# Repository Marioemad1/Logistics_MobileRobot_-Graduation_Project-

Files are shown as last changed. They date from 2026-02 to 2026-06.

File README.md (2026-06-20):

# Logistic Autonomous Robot

> A ROS 2 Humble autonomous logistics robot built for indoor navigation, station approach, cargo lifting, and future IoT / vision-assisted operation.

<p align="center">
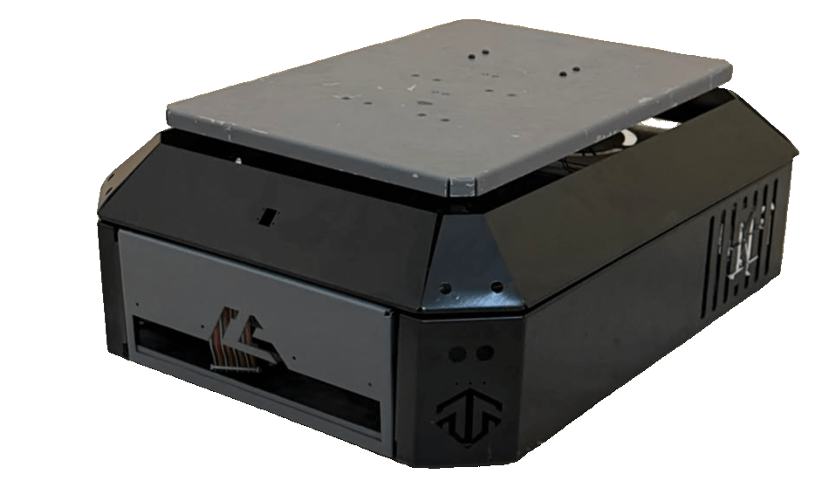
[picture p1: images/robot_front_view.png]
Robot front view placeholder
  
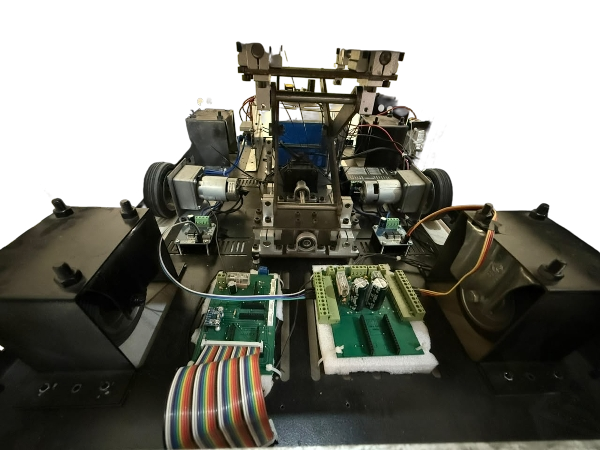
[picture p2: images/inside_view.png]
Robot electronics placeholder
  
</p>

https://github.com/user-attachments/assets/4f5d6dd3-665a-47e2-b4b6-8914b8b3f0d6

---

https://github.com/user-attachments/assets/4580d9f8-e7c1-4550-9aac-f85dd0c8e0f9

---

https://github.com/user-attachments/assets/9e4aa50d-fc3b-4a67-ba5b-2316206a55df

---

## Table of Contents

- [Project Overview](#project-overview)
- [Main Features](#main-features)
- [System Architecture](#system-architecture)
- [Hardware](#hardware)
- [Software Stack](#software-stack)
- [Repository Structure](#repository-structure)
- [ROS 2 Packages](#ros-2-packages)
- [Coordinate Frames and TF Tree](#coordinate-frames-and-tf-tree)
- [Serial Communication Protocol](#serial-communication-protocol)
- [Navigation and Localization](#navigation-and-localization)
- [Manual Engineering Edits](#manual-engineering-edits)
- [Installation](#installation)
- [Building the Workspace](#building-the-workspace)
- [Running the Robot](#running-the-robot)
- [Testing Checklist](#testing-checklist)
- [Troubleshooting](#troubleshooting)
- [Advantages of the Project](#advantages-of-the-project)
- [Roadmap](#roadmap)
- [Safety Notes](#safety-notes)
- [License](#license)

---

## Project Overview

This project is a complete ROS 2 mobile robot system designed for logistics-style operation. The robot is intended to:

1. Build or use a 2D map of an indoor environment.
2. Localize itself using LiDAR odometry and AMCL / EKF localization.
3. Navigate to target points using Nav2.
4. Approach loading / unloading stations.
5. Control a NEMA-driven lifting mechanism through an ESP32.
6. Support future camera-based station alignment and IoT command integration.

The robot was developed around a real physical platform, not only simulation. Because of that, the project includes several hardware-specific solutions such as custom `ros2_control` hardware interfaces, ESP32 serial control, LD06 LiDAR configuration, RF2O laser odometry, and conservative Nav2 tuning for a mechanically challenging differential-drive base.

---

## Main Features

- ROS 2 Humble workspace for a real mobile robot.
- Custom URDF / Xacro robot model with real CAD meshes.
- `ros2_control` integration for:
  - Differential-drive wheel control.
  - NEMA lift command interface.
  - Experimental IMU / LED / sensor interfaces.
- ESP32 serial protocol for motor and lift commands.
- LD06 LiDAR support.
- RF2O LiDAR odometry support.
- Optional EKF fusion using `robot_localization`.
- Nav2 configuration for slow and safe indoor testing.
- AMCL localization on a saved map.
- DWB local planner tuning for a large, unstable robot.
- YOLO-based camera alignment prototype.
- MQTT IoT bridge prototype.
- PS5 controller teleoperation support through `/cmd_vel`.

---

## System Architecture

```mermaid
architecture-beta

    group interface(cloud)[User Interface Layer]
    group navigation(cloud)[Navigation Localization Layer]
    group control(server)[ROS2 Control Layer]
    group embedded(server)[Embedded Hardware Layer]

    service ui(internet)[RViz2 PS5 IoT App] in interface

    service localization(database)[Map AMCL SLAM RF2O] in navigation
    service nav2(server)[Nav2 Planner Controller] in navigation
    service smoother(server)[Velocity Smoother] in navigation

    service ros2control(server)[ROS2 Control Controllers] in control
    service hardware(server)[Custom Hardware Interface LibSerial] in control

    service esp32(server)[ESP32 DevKit] in embedded
    service actuators(disk)[Drive Motors Lift Motor] in embedded

    ui:B --> T:nav2

    localization:R --> L:nav2
    nav2:R --> L:smoother

    smoother:B --> T:ros2control
    ros2control:B --> T:hardware

    hardware:B --> T:esp32
    esp32:B --> T:actuators
```

The navigation stack produces velocity commands. The velocity smoother limits acceleration and speed. The `diff_drive_controller` converts `/cmd_vel` into wheel joint velocity commands. The custom hardware interface converts those commands into serial messages for the ESP32.

---

## Hardware

| Component | Role |
|---|---|
| Differential-drive base | Main mobile platform |
| Two DC motors | Left and right wheel actuation |
| ESP32 DevKit / DevKitV1 | Low-level motor and NEMA control |
| NEMA stepper motor | Cargo lift mechanism |
| LD06 LiDAR | 2D scanning for SLAM, RF2O, AMCL, and obstacle detection |
| MPU6050 IMU | Experimental orientation / angular velocity source |
| Camera | Future station alignment and slot detection |
| Raspberry Pi or laptop | ROS 2 onboard computer |
| PS5 controller | Manual teleoperation |

### Mechanical Notes

The robot is approximately rectangular. The navigation footprint used during testing is:

```yaml
footprint: "[[0.41, 0.31], [0.41, -0.31], [-0.41, -0.31], [-0.41, 0.31]]"
```

This represents an estimated robot size of about:

```text
Length: 0.82 m
Width:  0.62 m
```

The robot has a known mechanical weakness in rotation. Therefore, the Nav2 configuration is intentionally tuned for slow angular velocity and low angular acceleration.

---

## Software Stack

| Layer | Technology |
|---|---|
| Operating system | Ubuntu Linux |
| ROS version | ROS 2 Humble |
| Robot model | URDF / Xacro |
| Control framework | `ros2_control` |
| Motor controller | `diff_drive_controller` |
| Lift controller | `forward_command_controller` |
| Navigation | Nav2 |
| Localization | AMCL, RF2O, optional EKF |
| Mapping | SLAM Toolbox / Cartographer workflow |
| Low-level MCU | ESP32 Arduino code |
| Serial library | LibSerial |
| Vision prototype | OpenCV + YOLO |
| IoT prototype | MQTT / Paho |

---

## Repository Structure

```text
src/
├── camera_model/          # YOLO / camera alignment prototype
├── controller/            # High-level action controller prototype
├── hw_interface/          # Custom ros2_control hardware interfaces
├── iot_bridge/            # MQTT IoT bridge prototype
├── robot_bringup/         # Launch files and YAML configs
└── robot_description/     # URDF, Xacro, meshes, RViz config
```

---

## ROS 2 Packages

### `robot_description`

This package contains the robot model.

Important files:

```text
robot_description/urdf/my_robot.urdf.xacro
robot_description/urdf/chassis.urdf.xacro
robot_description/urdf/wheels_mobile_robot.urdf.xacro
robot_description/urdf/sensors.urdf.xacro
robot_description/urdf/ros2_control.urdf.xacro
robot_description/meshes/*.STL
robot_description/rviz2/default.rviz
```

Main responsibilities:

- Defines `base_link`, wheels, sensors, LiDAR, camera, ultrasonic sensor meshes, and lift-related links.
- Defines fixed transforms between the robot body and sensors.
- Defines `ros2_control` systems for the mobile base and NEMA lift.
- Provides CAD mesh visualization in RViz.

Important LiDAR joint:

```xml
<joint name="base_scan_joint" type="fixed">
    <parent link="base_link"/>
    <child link="base_laser"/>
    <origin xyz="0.412 0.0 0.038" rpy="0.0 0.0 -1.57"/>
</joint>
```

The `-1.57` yaw was manually selected after RViz testing so that a real wall in front of the robot appears in front of the robot in RViz.

---

### `robot_bringup`

This package contains launch files and configuration files.

Important files:

```text
robot_bringup/config/my_robot_controllers.yaml
robot_bringup/config/logi.yaml
robot_bringup/config/ekf.yaml
robot_bringup/launch/ros2_control_mobile_base.xml
robot_bringup/launch/localization.lanch.xml
robot_bringup/launch/robot_state_publisher.launch.py
```

Main responsibilities:

- Starts `robot_state_publisher`.
- Starts `ros2_control_node`.
- Spawns the wheel controller and NEMA controller.
- Loads Nav2 parameters.
- Loads EKF / localization configuration.

---

### `hw_interface`

This is the core hardware package. It implements custom `ros2_control` `SystemInterface` plugins.

Important files:

```text
hw_interface/src/mobile_base_hardware_interface.cpp
hw_interface/src/nema_lift_hardware_interface.cpp
hw_interface/include/hw_interface/shared_serial_port.hpp
hw_interface/src/mpu6050_hardware_interface.cpp
hw_interface/src/led_hardware_interface.cpp
hw_interface/src/ultrasonic_sensor.cpp
hw_interface/src/battery_pr_adc_vol.cpp
hw_interface/hw_interface.xml
```

Main responsibilities:

- Opens the ESP32 serial port.
- Sends wheel velocity commands to the ESP32.
- Sends NEMA lift commands to the ESP32.
- Exports wheel command/state interfaces to `diff_drive_controller`.
- Exports NEMA command/state interface to `forward_command_controller`.
- Provides experimental sensor interfaces.

The project uses a singleton shared serial port:

```cpp
SharedSerialPort::getInstance()
```

This prevents the mobile-base hardware plugin and the NEMA hardware plugin from creating two separate serial connections to the same ESP32.

---

### `controller`

This package is the high-level mission controller prototype.

It is intended to coordinate:

1. Navigation to a pickup point.
2. Lift command.
3. Navigation to a drop-off point.
4. Lower command.
5. Return or continue to the next station.

The package uses:

```python
nav2_simple_commander.BasicNavigator
geometry_msgs.msg.PoseStamped
```

During development, the NEMA feedback was difficult to make fully reliable through shared serial reading, so the workflow can temporarily use a fixed delay after lift/lower commands for time-saving testing.

---

### `camera_model`

This package contains a prototype camera alignment node.

Main idea:

```text
camera image -> YOLO detection -> box center error -> Twist command
```

It subscribes to:

```text
/camera/image_raw
```

and publishes alignment velocity commands to:

```text
/cmd_vel
```

This is planned for station alignment after Nav2 reaches a pre-entry pose.

---

### `iot_bridge`

This package contains an MQTT bridge prototype.

It connects to an MQTT broker and subscribes to robot command topics such as:

```text
robot/command
```

It also publishes robot online/offline status using MQTT Last Will behavior.

This package is prepared for future cloud / dashboard integration.

---

## Coordinate Frames and TF Tree

The intended TF tree is:

```text
map
└── odom
    └── base_footprint
        └── base_link
            └── base_laser
```

Frame meanings:

| Frame | Meaning |
|---|---|
| `map` | Global fixed frame from map / localization |
| `odom` | Continuous odometry frame |
| `base_footprint` | 2D robot base frame projected onto the floor |
| `base_link` | Main robot body frame |
| `base_laser` | LiDAR sensor frame |

Important rule:

- Only one source should publish `odom -> base_footprint` or `odom -> base_link`.
- During RF2O-only testing, RF2O may publish odom TF.
- When EKF is used, RF2O should publish odometry data but not TF, and EKF should publish the odom TF.

---

## Serial Communication Protocol

The ESP32 receives simple ASCII commands from ROS 2.

### Wheel Command Format

```text
R:<right_velocity>,L:<left_velocity>\n
```

Example:

```text
R:0.120000,L:0.120000
```

This command is generated by the mobile-base hardware interface from the `diff_drive_controller` wheel commands.

### NEMA Lift Command Format

```text
N:1.0\n    # lift up
N:0.0\n    # stop / reset latch
N:-1.0\n   # lower down
```

The NEMA hardware interface converts `Float64MultiArray` commands into these serial messages.

ROS command example:

```bash
ros2 topic pub --once /Nema_controller/commands std_msgs/msg/Float64MultiArray "{data: [1.0]}"
```

### ESP32 Feedback

The ESP32 can print:

```text
1
-1
```

These values represent lift-up or lift-down completion feedback.

During testing, this feedback was sometimes lost because multiple hardware interfaces were reading from the same serial port. The final design should keep only one serial reader for feedback or use a clear serial message router.

---

## Navigation and Localization

### Mapping

The project supports mapping using SLAM tools with LD06 LiDAR data.

Recommended mapping TF chain:

```text
map -> odom -> base_footprint -> base_link -> base_laser
```

### Localization

The navigation workflow uses:

- Saved map from mapping.
- AMCL for global localization.
- RF2O for LiDAR odometry.
- Optional EKF fusion using `robot_localization`.

### RF2O

RF2O estimates robot motion directly from laser scans. This is useful because the robot does not currently rely on wheel encoders for odometry.

Recommended RF2O parameters during standalone testing:

```xml
<param name="laser_scan_topic" value="/scan"/>
<param name="odom_topic" value="/odom_rf2o"/>
<param name="base_frame_id" value="base_footprint"/>
<param name="odom_frame_id" value="odom"/>
<param name="publish_tf" value="true"/>
<param name="freq" value="10.0"/>
```

When EKF is active:

```xml
<param name="publish_tf" value="false"/>
```

### Nav2 Tuning Philosophy

The robot has a mechanical rotation issue, so Nav2 is tuned to be slow and smooth.

Recommended safe testing values:

| Parameter | Value | Reason |
|---|---:|---|
| `max_vel_x` | `0.12` | Slow forward motion |
| `max_vel_theta` | `0.35` | Soft turning |
| `acc_lim_x` | `0.25` | Avoid jerky starts |
| `acc_lim_theta` | `0.5` | Avoid aggressive rotation |
| `inflation_radius` | `0.65` | Wide safety field near walls |
| `cost_scaling_factor` | `3.0` | Smooth cost decay |
| `BaseObstacle.scale` | `1.0` | Stronger obstacle avoidance |
| `PathAlign.scale` | `12.0` | Moderate path alignment |
| `GoalAlign.scale` | `8.0` | Moderate goal alignment |
| `RotateToGoal.scale` | `8.0` | Avoid violent final rotation |
| `footprint_padding` | `0.02` | Small safety margin |

The robot should first be validated in open space before attempting station entry.

---

## Manual Engineering Edits

This section documents the important manual changes made during development.

### 1. LD06 LiDAR Angle Range Patch

The LD06 driver originally published scans from:

```text
0 -> 2π
```

RF2O works better with scans normalized to:

```text
-π -> +π
```

Manual driver patch:

```cpp
angle_min = -M_PI;
angle_max = M_PI;
```

and after computing the scan angle:

```cpp
if (angle > M_PI) {
  angle -= 2 * M_PI;
}
```

This makes the scan easier for RF2O and TF visualization.

### 2. LiDAR Frame Rotation

The LiDAR frame was manually corrected in the URDF:

```xml
<origin xyz="0.412 0.0 0.038" rpy="0.0 0.0 -1.57"/>
```

This was verified in RViz by placing a wall in front of the robot and confirming that the scan appears in front of the robot.

### 3. Front-Half LiDAR Crop

Because the LD06 is mounted at the front of the robot and the robot body blocks or corrupts part of the scan, the driver can crop the scan angle to use only the useful field of view.

This improves obstacle interpretation for the physical mounting, but it also reduces RF2O / SLAM information. The robot should move slowly while mapping.

### 4. `diff_drive_controller` TF Disabled

The wheel controller publishes odometry, but TF broadcasting is disabled:

```yaml
enable_odom_tf: false
```

This prevents TF conflicts because RF2O or EKF should own the odometry transform.

### 5. Unstamped Velocity Commands

The project uses unstamped velocity commands for simplicity:

```yaml
enable_stamped_cmd_vel: false
use_stamped_vel: false
```

This keeps the command chain simple:

```text
Nav2 -> velocity_smoother -> /cmd_vel -> diff_drive_controller
```

### 6. ESP32 DevKitV1 Reset / Enable Handling

Some ESP32 DevKitV1 boards need USB serial DTR / RTS toggling similar to Arduino IDE reset behavior.

For LibSerial, the correct functions are:

```cpp
SetDTR()
SetRTS()
```

not:

```cpp
setDTR()
setRTS()
```

Example reset logic:

```cpp
shared_serial.port->SetDTR(true);
shared_serial.port->SetRTS(false);
std::this_thread::sleep_for(std::chrono::milliseconds(100));

shared_serial.port->SetDTR(false);
shared_serial.port->SetRTS(false);
std::this_thread::sleep_for(std::chrono::milliseconds(500));
```

This should be applied only once after the serial port opens, not separately in every hardware plugin.

### 7. NEMA One-Shot Command Logic

ROS 2 controllers call `write()` repeatedly. If the NEMA command is sent every cycle, the ESP32 may receive repeated lift commands.

The intended logic is:

```text
Send N:1.0 once when command changes to lift
Send N:-1.0 once when command changes to lower
Send N:0.0 once to reset / stop
```

This prevents command flooding.

### 8. Nav2 Safety Retuning

The original Nav2 configuration was too aggressive for this robot. It was retuned to:

- Reduce forward speed.
- Reduce angular speed.
- Reduce acceleration.
- Increase inflation radius.
- Lower cost scaling factor for smoother wall avoidance.
- Increase obstacle critic importance.
- Reduce path and goal critic pressure.

This makes the robot safer around walls and less likely to rotate violently.

### 9.PCB:
<p align="center">
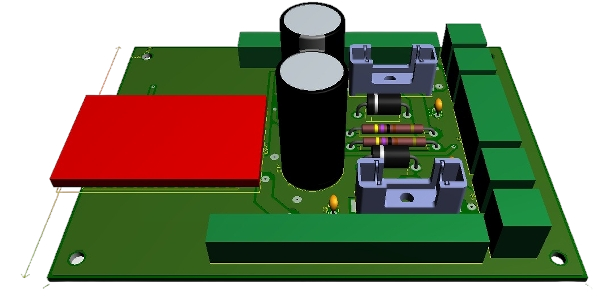
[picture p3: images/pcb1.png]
pcb1
  
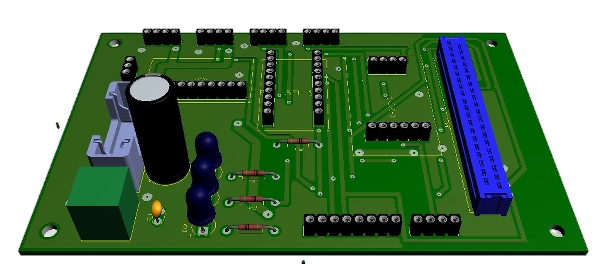
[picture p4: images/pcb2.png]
pcb2
  
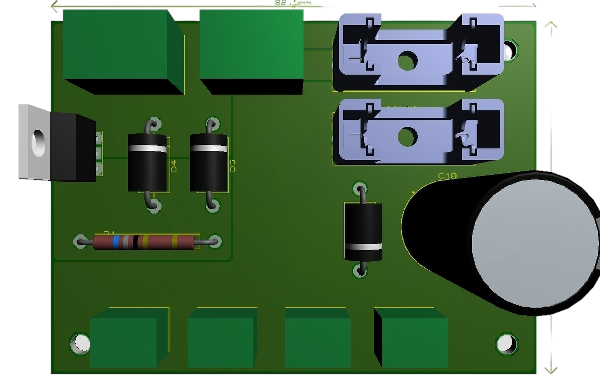
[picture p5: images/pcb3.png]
pcb3
  
</p>

---

## Installation

### 1. Install ROS 2 Humble

Follow the official ROS 2 Humble installation guide for Ubuntu.

### 2. Install Required ROS Packages

```bash
sudo apt update
sudo apt install -y \
  ros-humble-ros2-control \
  ros-humble-ros2-controllers \
  ros-humble-diff-drive-controller \
  ros-humble-joint-state-broadcaster \
  ros-humble-forward-command-controller \
  ros-humble-robot-state-publisher \
  ros-humble-xacro \
  ros-humble-rviz2 \
  ros-humble-nav2-bringup \
  ros-humble-navigation2 \
  ros-humble-robot-localization \
  ros-humble-slam-toolbox \
  ros-humble-tf-transformations \
  ros-humble-joy \
  ros-humble-teleop-twist-joy
```

### 3. Install System Dependencies

```bash
sudo apt install -y \
  libserial-dev \
  liblgpio-dev \
  python3-pip \
  python3-colcon-common-extensions
```

Optional Python dependencies:

```bash
pip3 install paho-mqtt opencv-python ultralytics
```

---

## Building the Workspace

Clone the repository into a ROS 2 workspace:

```bash
mkdir -p ~/logistic_ws/src
cd ~/logistic_ws/src

git clone <YOUR_REPOSITORY_URL> .
```

Build:

```bash
cd ~/logistic_ws
colcon build --symlink-install
source install/setup.bash
```

If only hardware interface code changed:

```bash
colcon build --symlink-install --packages-select hw_interface
source install/setup.bash
```

If only bringup / config changed:

```bash
colcon build --symlink-install --packages-select robot_bringup
source install/setup.bash
```

---

## Arduino / ESP32 Setup

For ESP32 DevKitV1 in Arduino IDE:

```text
Board: ESP32 Dev Module
Upload Speed: 115200
CPU Frequency: 240MHz
Flash Frequency: 80MHz
Flash Mode: QIO or DIO if upload fails
Partition Scheme: Default 4MB
```

If upload hangs on `Connecting...`, hold the `BOOT` button until upload starts.

The ESP32 firmware should use:

```cpp
Serial.begin(115200);
```

The ROS hardware interface must use the same baud rate:

```cpp
LibSerial::BaudRate::BAUD_115200
```

---

## Serial Port Setup

Find the ESP32 and LiDAR ports:

```bash
ls -l /dev/ttyUSB* /dev/ttyACM* 2>/dev/null
ls -l /dev/serial/by-id/
```

Use stable `/dev/serial/by-id/...` names when possible.

The ESP32 and LiDAR must not use the same serial device.

Update the hardcoded ESP32 port in the hardware interface if needed:

```cpp
port_ = "/dev/serial/by-id/<YOUR_ESP32_ID>";
```

---

## Running the Robot

### 1. Start Low-Level Control

```bash
source /opt/ros/humble/setup.bash
source ~/logistic_ws/install/setup.bash

ros2 launch robot_bringup ros2_control_mobile_base.xml
```

Check controllers:

```bash
ros2 control list_controllers
```

Expected controllers:

```text
joint_state_broadcaster
 diff_drive_controller
 Nema_controller
```

### 2. Test Wheel Motion

Test forward motion slowly:

```bash
ros2 topic pub --once /cmd_vel geometry_msgs/msg/Twist \
"{linear: {x: 0.05}, angular: {z: 0.0}}"
```

Test rotation slowly:

```bash
ros2 topic pub --once /cmd_vel geometry_msgs/msg/Twist \
"{linear: {x: 0.0}, angular: {z: 0.15}}"
```

The robot must move in the expected direction before Nav2 testing.

### 3. Test NEMA Lift

```bash
ros2 topic pub --once /Nema_controller/commands std_msgs/msg/Float64MultiArray \
"{data: [1.0]}"
```

Stop / reset:

```bash
ros2 topic pub --once /Nema_controller/commands std_msgs/msg/Float64MultiArray \
"{data: [0.0]}"
```

Lower:

```bash
ros2 topic pub --once /Nema_controller/commands std_msgs/msg/Float64MultiArray \
"{data: [-1.0]}"
```

### 4. Start Localization

```bash
ros2 launch robot_bringup localization.lanch.xml
```

> Note: the current file name contains `lanch` instead of `launch`. Rename it if desired, but keep commands consistent.

### 5. Start Navigation

Use your Nav2 launch file for the saved map workflow. The configuration file is:

```text
robot_bringup/config/logi.yaml
```

Before moving the real robot, verify the command types:

```bash
ros2 topic type /cmd_vel
ros2 topic type /cmd_vel_smoothed
ros2 topic type /diff_drive_controller/cmd_vel_unstamped
```

The current configuration is intended for unstamped commands:

```text
geometry_msgs/msg/Twist
```

### 6. PS5 Controller Teleoperation

Install packages:

```bash
sudo apt install ros-humble-joy ros-humble-teleop-twist-joy joystick
```

Check joystick:

```bash
ls /dev/input/js*
jstest /dev/input/js0
```

Run joystick node:

```bash
ros2 run joy joy_node --ros-args -p dev:=/dev/input/js0
```

Run teleop:

```bash
ros2 run teleop_twist_joy teleop_node --ros-args -r cmd_vel:=/cmd_vel
```

---

## Testing Checklist

Before autonomous Nav2 testing:

- [ ] ESP32 is detected at the correct serial port.
- [ ] LiDAR is detected at a different serial port.
- [ ] `ros2 control list_controllers` shows active controllers.
- [ ] `/scan` publishes valid LiDAR data.
- [ ] TF tree is complete.
- [ ] `/cmd_vel` drives the robot forward correctly.
- [ ] Positive angular velocity rotates the robot in the expected direction.
- [ ] NEMA lift responds to `[1.0]`, `[0.0]`, and `[-1.0]` commands.
- [ ] Nav2 command type is consistent: stamped or unstamped, not mixed.
- [ ] Initial pose is set correctly in RViz.
- [ ] First Nav2 goal is in open space, not near walls.

Recommended first Nav2 test:

```text
Goal distance: 0.5 m to 1.0 m
Environment: open area
Speed: low
Operator: ready to cut power
```

---

## Troubleshooting

### ESP32 does not respond after changing board

Check:

```bash
ls -l /dev/serial/by-id/
```

Update the serial port in the hardware interface.

If the board needs reset through DTR / RTS, add the reset sequence after opening the serial port.

### VS Code shows missing ROS headers

This is usually an IntelliSense problem, not a build problem.

Trust:

```bash
colcon build --symlink-install
```

If the build passes, the ROS code is valid.

### Robot drives into walls

Check these first:

1. Is `/cmd_vel` direction correct?
2. Is initial pose correct in RViz?
3. Is LiDAR scan aligned with the robot frame?
4. Is Nav2 using unstamped or stamped commands consistently?
5. Are costmap obstacles visible in RViz?
6. Is the robot moving too fast?

### Robot refuses to enter station

The robot is about 0.62 m wide and the station is about 0.80 m wide, leaving about 0.09 m clearance per side.

Recommended strategy:

```text
Nav2 -> pre-entry point outside station
Action server -> slow straight drive into station
NEMA -> lift/lower
Action server -> slow straight reverse out
Nav2 -> next goal
```

Do not make the whole Nav2 costmap unsafe just to enter the station.

### RF2O rotates while robot is fixed

This can happen with partial LiDAR field of view and angled walls.

Possible solutions:

- Keep robot motion slow during mapping.
- Add deadband / jump rejection to RF2O.
- Add IMU fusion through EKF.
- Improve LiDAR view if possible.

---

## Advantages of the Project

- Built for a real physical robot, not only simulation.
- Full ROS 2 architecture from URDF to Nav2.
- Custom `ros2_control` hardware interfaces.
- ESP32-based low-level control keeps motor code simple and separated from ROS.
- LiDAR-only odometry makes the project usable even without wheel encoders.
- Modular structure allows independent development of navigation, lift control, vision, and IoT.
- Safe Nav2 tuning for a mechanically imperfect platform.
- Expandable to camera-based docking and cloud-based task assignment.
- Good educational example of real-world ROS 2 integration problems and solutions.

---

## Roadmap

- [ ] Replace hardcoded serial port with ROS parameters.
- [ ] Add stable `/dev/serial/by-id` documentation for each robot.
- [ ] Add one-shot NEMA command protection directly in the hardware interface.
- [ ] Add robust ESP32 serial feedback parser.
- [ ] Add RF2O stationary deadband / jump rejection patch.
- [ ] Add full Nav2 launch file to the repository.
- [ ] Add station pre-entry and straight docking routine.
- [ ] Add camera alignment after Nav2 pre-entry.
- [ ] Add IoT task-to-action connection.
- [ ] Add emergency stop hardware and software interface.
- [ ] Add final robot photos and demonstration videos.

---

## Safety Notes

This robot is a real moving platform. Always test slowly.

Recommended safety rules:

- Test with wheels lifted before first motion.
- Keep a physical power switch or emergency stop nearby.
- Never test full Nav2 near walls before verifying `/cmd_vel` direction.
- Keep Nav2 speed low while tuning.
- Do not rely on collision monitor until its polygons are correctly sized and the node is confirmed running.
- Do not run station docking until open-area navigation is stable.

---

## License

Add your selected license here.

Recommended options:

- MIT License for simple open-source use.
- Apache 2.0 if you want a more ROS-like permissive license.

---

## Author

Developed by Mario Emad Boles

GitHub: `<your-github-profile>`

---

## Media To Add Before Publishing

Create these folders:

```bash
mkdir -p docs/images docs/videos
```

Suggested files:

```text
docs/images/robot_front.jpg
docs/images/robot_side.jpg
docs/images/electronics.jpg
docs/images/rviz_map.png
docs/images/nav2_path.png

docs/videos/mapping_demo.mp4
docs/videos/navigation_demo.mp4
docs/videos/station_demo.mp4
```

Then update the links at the top of this README.

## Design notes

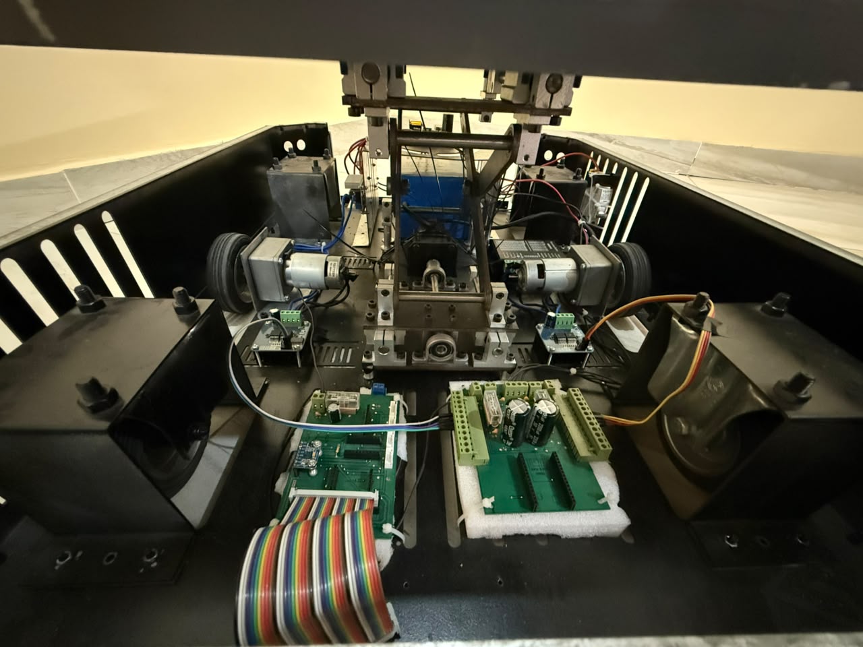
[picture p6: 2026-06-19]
images/inside-view.jpg

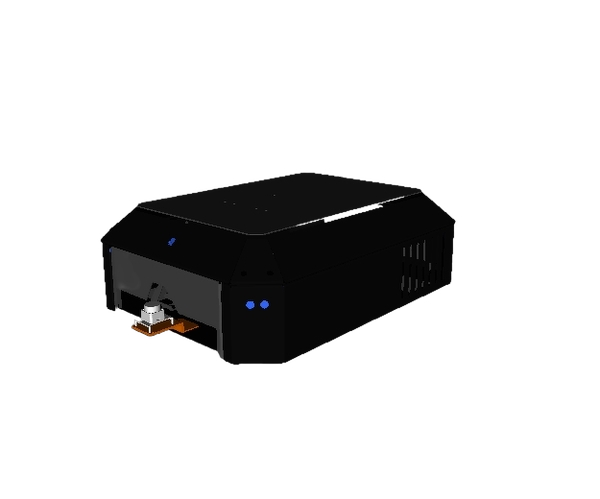
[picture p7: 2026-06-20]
images/SIM_VIEW.png

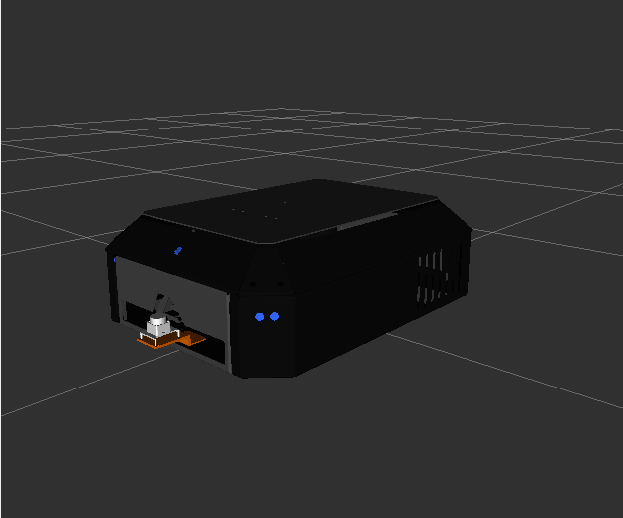
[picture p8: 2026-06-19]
images/simulation_view.png

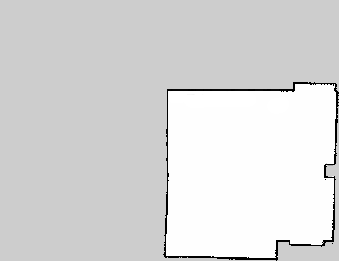
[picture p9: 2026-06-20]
images/final_map.png

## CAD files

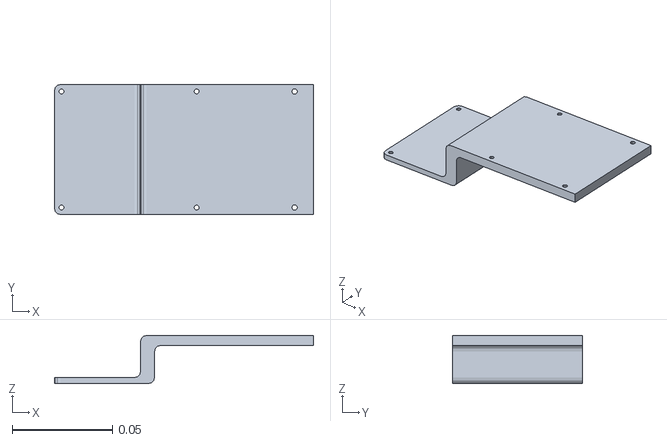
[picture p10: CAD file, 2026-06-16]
robot_description/meshes/liDAR_SPACER.STL
0.129 x 0.065 x 0.024

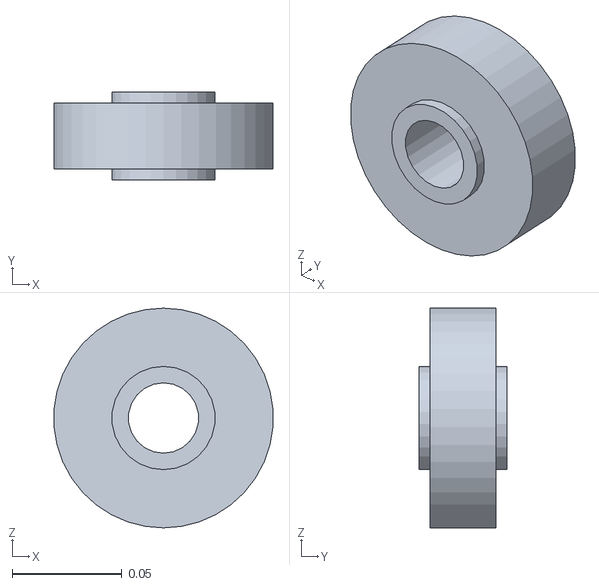
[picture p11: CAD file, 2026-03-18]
robot_description/meshes/WHEELLEFT.STL
0.0997 x 0.04 x 0.1

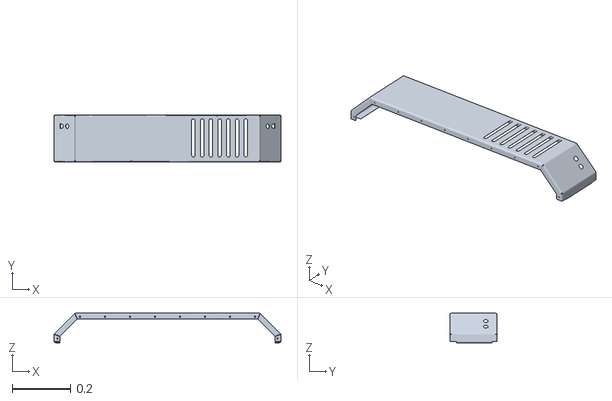
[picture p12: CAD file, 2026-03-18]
robot_description/meshes/LEFTSIDE.STL
0.781 x 0.163 x 0.102

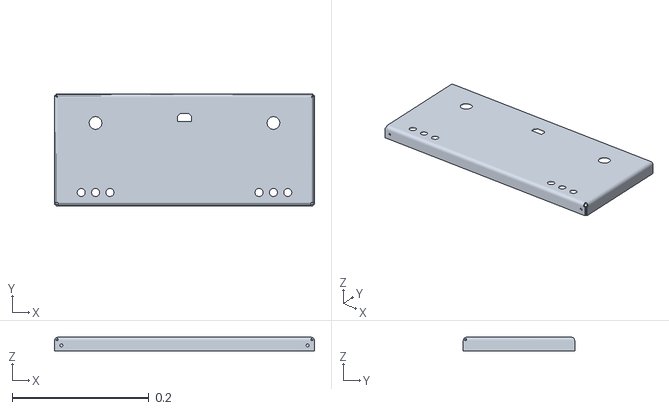
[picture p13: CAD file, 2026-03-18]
robot_description/meshes/BACKFACE.STL
0.38 x 0.163 x 0.02

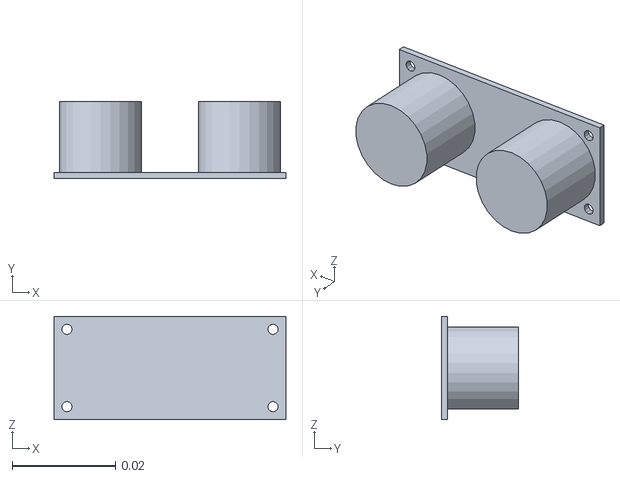
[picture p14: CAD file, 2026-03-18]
robot_description/meshes/ULTRASONIC2.STL
0.045 x 0.015 x 0.02

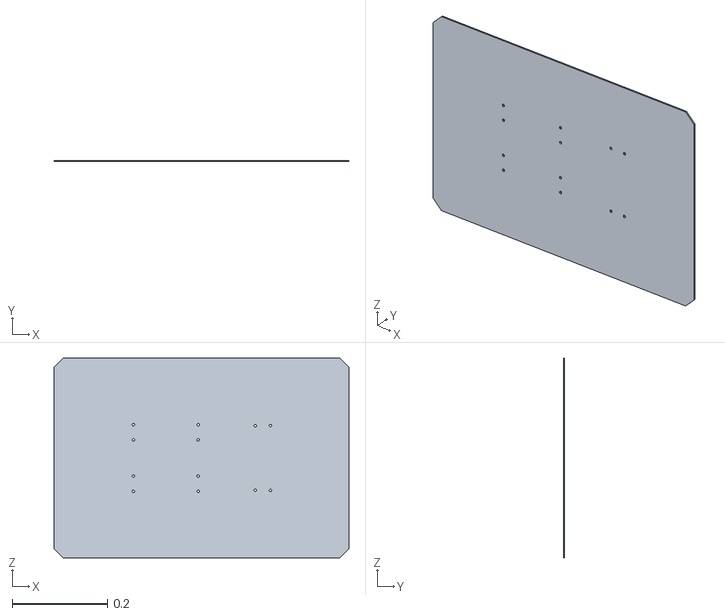
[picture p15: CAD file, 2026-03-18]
robot_description/meshes/TOPBASE.STL
0.62 x 0.003 x 0.42

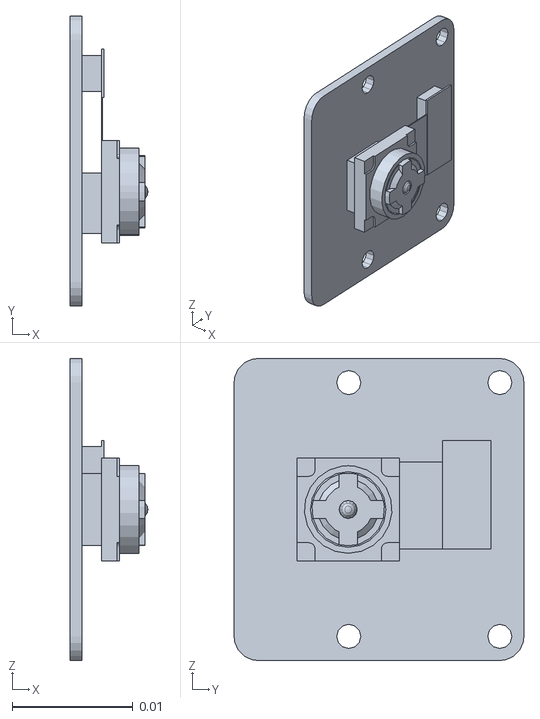
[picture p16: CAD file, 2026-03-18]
robot_description/meshes/CAMRAS.STL
0.00645 x 0.024 x 0.025

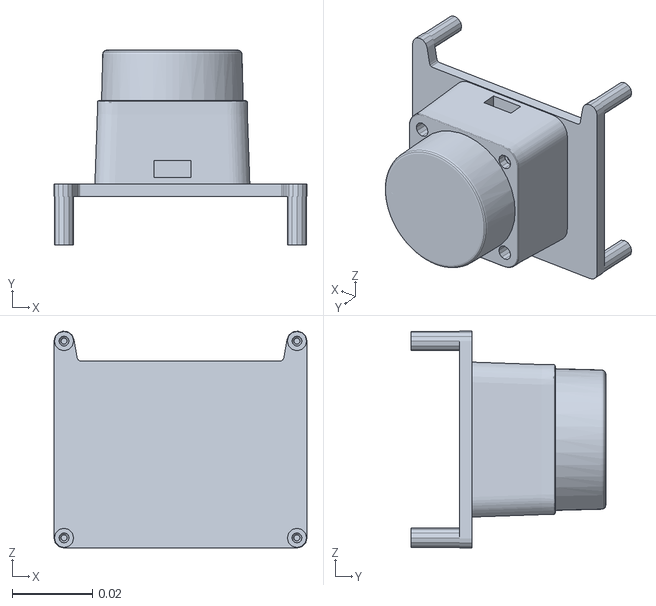
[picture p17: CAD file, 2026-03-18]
robot_description/meshes/LIDAR.STL
0.063 x 0.0485 x 0.054

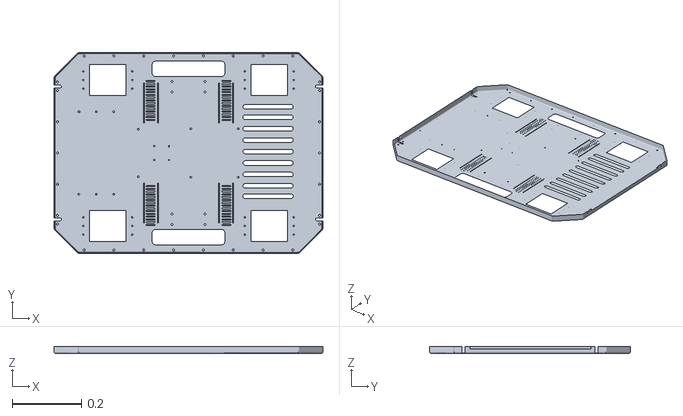
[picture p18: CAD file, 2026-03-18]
robot_description/meshes/base_link.STL
0.776 x 0.58 x 0.02

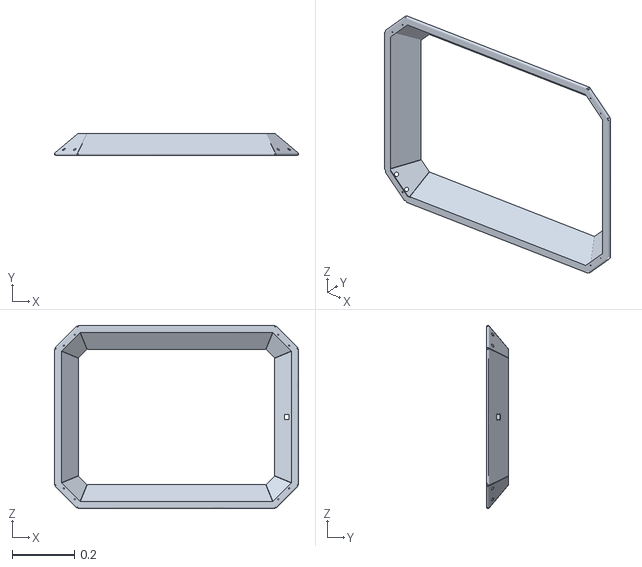
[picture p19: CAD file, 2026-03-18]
robot_description/meshes/FLANGE.STL
0.787 x 0.0707 x 0.59

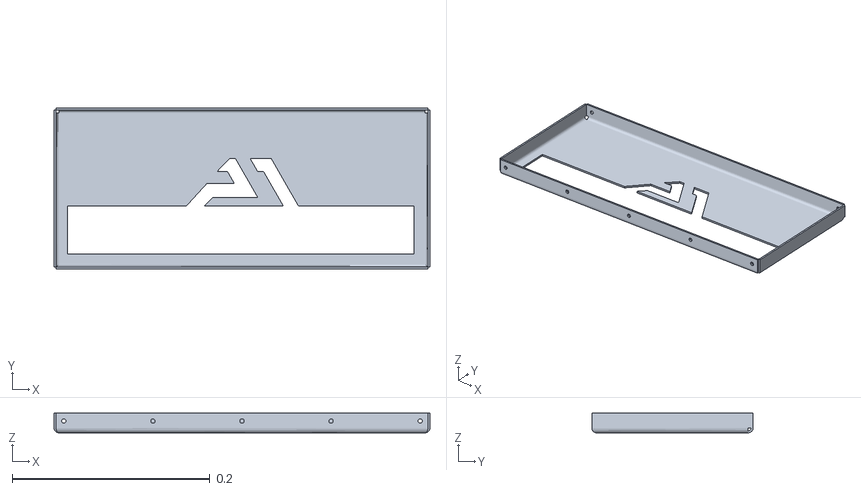
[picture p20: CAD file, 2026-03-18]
robot_description/meshes/FRONTFACE.STL
0.38 x 0.163 x 0.02

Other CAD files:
robot_description/meshes/WHEELRIGHT.STL
robot_description/meshes/RIGHTSIDE.STL
robot_description/meshes/ULTRASONIC1.STL
robot_description/meshes/ULTRASONIC4.STL
robot_description/meshes/ULTRASONIC3.STL
robot_description/meshes/lidar_spacer.STL

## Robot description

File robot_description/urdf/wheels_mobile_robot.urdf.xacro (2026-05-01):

<?xml version="1.0"?>
<robot xmlns:xacro="http://www.ros.org/wiki/xacro">

    <link name="right_wheel_link">
        <visual>
            <origin xyz="0 0 0" rpy="0 0 0" />
            <geometry>
                <mesh filename="package://robot_description/meshes/WHEELRIGHT.STL" />
            </geometry>
            <material name="Black_wheels"/>
        </visual>
        <collision>
            <origin xyz="0 0 0" rpy="0 0 0" />
            <geometry>
                <cylinder radius="0.05" length="0.03"/>
            </geometry>
        </collision>
        <inertial>
            <mass value="0.27052" />
            <origin xyz="0 0 0" />
            <inertia ixx="0.00020379" ixy="1.8231E-022" ixz="-1.0447E-037" iyy="0.00036168" iyz="6.2575E-022" izz="0.00020379" />
        </inertial>
    </link>

    <link name="left_wheel_link">
        <visual>
            <origin xyz="0 0 0" rpy="0 0 0" />
            <geometry>
                <mesh filename="package://robot_description/meshes/WHEELRIGHT.STL" />
            </geometry>
            <material name="Black_wheels"/>
        </visual>
        <collision>
            <origin xyz="0 0 0" rpy="0 0 0" />
            <geometry>
                <cylinder radius="0.05" length="0.03"/>
            </geometry>
        </collision>
        <inertial>
            <mass value="0.27052" />
            <origin xyz="0 0 0" />
            <inertia ixx="0.00020379" ixy="1.8231E-022" ixz="-1.0447E-037" iyy="0.00036168" iyz="6.2575E-022" izz="0.00020379" />
        </inertial>
    </link>


    <link name="front_caster_wheel_link">
        <visual>
            <origin xyz="0 0 0" rpy="0 0 0" />
            <geometry>
                <sphere radius="0.0079275"/>
            </geometry>
            <material name="Black_wheels"/>
        </visual>
        <collision>
            <origin xyz="0 0 0" rpy="0 0 0" />
            <geometry>
                <sphere radius="0.0079275"/>
            </geometry>
        </collision>
        <xacro:sphere_inertia m="2.5" r="${0.0079275/2.0}" xyz="0 0 0" rpy="0 0 0" />
    </link>

    <link name="back_caster_wheel_link">
        <visual>
            <origin xyz="0 0 0" rpy="0 0 0" />
            <geometry>
                <sphere radius="0.0079275"/>
            </geometry>
            <material name="Black_wheels"/>
        </visual>
        <collision>
            <origin xyz="0 0 0" rpy="0 0 0" />
            <geometry>
                <sphere radius="0.0079275"/>
            </geometry>
        </collision>
        <xacro:sphere_inertia m="2.5" r="${0.0079275/2.0}" xyz="0 0 0" rpy="0 0 0" />
    </link>


    <joint name="base_right_wheel_joint" type="continuous">
        <parent link="base_link"/>
        <child link="right_wheel_link"/>
        <axis xyz="0 1 0"/>
        <origin xyz="0.00031675 -0.243 0.034145" rpy="0 0 0"/>
    </joint>

    <joint name="base_left_wheel_joint" type="continuous">
        <parent link="base_link"/>
        <child link="left_wheel_link"/>
        <axis xyz="0 1 0"/>
        <origin xyz="0.00031675 0.243 0.034145" rpy="0 0 0"/>
    </joint>

    <joint name="base_caster_front_joint" type="fixed">
        <parent link="base_link"/>
        <child link="front_caster_wheel_link"/>
        <origin xyz="0.344 0.0 -0.0094275" rpy="0.0 0.0 0.0"/>
    </joint>

    <joint name="base_caster_back_joint" type="fixed">
        <parent link="base_link"/>
        <child link="back_caster_wheel_link"/>
        <origin xyz="-0.344 0.0 -0.0094275" rpy="0.0 0.0 0.0"/>
    </joint>
    
    
    
</robot>

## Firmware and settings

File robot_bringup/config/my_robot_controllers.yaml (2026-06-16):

controller_manager:
  ros__parameters:
    update_rate: 50

    joint_state_broadcaster:
      type: joint_state_broadcaster/JointStateBroadcaster

    diff_drive_controller:
      type: diff_drive_controller/DiffDriveController

    Nema_controller:
      type: forward_command_controller/ForwardCommandController 

    #imu_broadcaster:
      #type: imu_sensor_broadcaster/IMUSensorBroadcaster

diff_drive_controller:
  ros__parameters:
    left_wheel_names: ["base_left_wheel_joint"]
    right_wheel_names: ["base_right_wheel_joint"]

    use_stamped_vel: false

    wheel_separation: 0.49
    wheel_radius: 0.05

    odom_frame_id: "odom"
    base_frame_id: "base_footprint"

    pose_covariance_diagonal: [0.001, 0.001, 0.001, 0.001, 0.001, 0.01]
    twist_covariance_diagonal: [0.001, 0.001, 0.001, 0.001, 0.001, 0.01]

    enable_odom_tf: false
    publish_rate: 50.0 
    position_feedback: false
    open_loop: true

    linear.x.has_velocity_limits: true
    linear.x.max_velocity: 1.0
    linear.x.min_velocity: -1.0

    angular.z.has_velocity_limits: true
    angular.z.max_velocity: 1.0
    angular.z.min_velocity: -1.0



Nema_controller:
  ros__parameters:
    joints:
      - base_esp_joint
    interface_name: state

#imu_broadcaster:
  #ros__parameters:
    #sensor_name: imu_link     # must match URDF
    #frame_id: base_link         # or imu_link

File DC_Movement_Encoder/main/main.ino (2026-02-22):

// #include "DC_Movement_Encoder.hpp"

// // Pin Assignments for BTS7960 and Encoders
// const int L_LPWM = 16;
// const int L_RPWM = 17;
// const int R_LPWM = 18;
// const int R_RPWM = 19;
// const int L_ENCA = 32;
// const int L_ENCB = 33;
// const int R_ENCA = 25;
// const int R_ENCB = 26;

// // Robot Physical Constants
// const float WHEEL_DIAM = 100.0; // mm
// const float WHEEL_BASE = 300.0; // mm

// // Create Drivetrain instance
// RobotDrivetrain robot(L_LPWM, L_RPWM, R_LPWM, R_RPWM, L_ENCA, L_ENCB, R_ENCA,
//                       R_ENCB);

// void setup() {
//   Serial.begin(115200);

//   // Initialize PWM and interrupts via global pointer g_drivetrain
//   robot.init();

//   // Set PID gains for a stable 100kg chassis response
//   robot.setPIDGains(0.8, 0.01, 0.1);

//   Serial.println("--- AMR MOTION TEST STARTING ---");
//   delay(3000); // Safety delay to place robot on floor
// }

// void loop() {
//   // 1. Move Forward 500mm
//   Serial.println("Action: Forward 500mm");
//   robot.moveDistance(500.0, 150, WHEEL_DIAM);
//   waitForTarget();

//   // 2. Pivot Turn Right 90 Degrees
//   Serial.println("Action: Rotate Right 90°");
//   robot.rotateAngle(90.0, 150, WHEEL_BASE, WHEEL_DIAM);
//   waitForTarget();

//   // 3. Move Backward 500mm
//   Serial.println("Action: Backward 500mm");
//   robot.moveDistance(-500.0, 150, WHEEL_DIAM);
//   waitForTarget();

//   // 4. Pivot Turn Left 90 Degrees
//   Serial.println("Action: Rotate Left 90°");
//   robot.rotateAngle(-90.0, 150, WHEEL_BASE, WHEEL_DIAM);
//   waitForTarget();

//   Serial.println("--- Full Test Cycle Complete ---");
//   delay(5000); // Pause before repeating
// }

// /**
//  * Helper function to block execution until the robot reaches its target
//  * while printing real-time encoder feedback to the Serial Monitor.
//  */
// void waitForTarget() {
//   while (!robot.updatePositionControl()) {
//     static unsigned long lastLog = 0;
//     if (millis() - lastLog > 200) {
//       Serial.print("L_Pos: ");
//       Serial.print(robot.getLeftPosition());
//       Serial.print(" | R_Pos: ");
//       Serial.print(robot.getRightPosition());
//       Serial.print(" | Speed: ");
//       Serial.print(robot.getLeftSpeed());
//       Serial.println(" RPM");
//       lastLog = millis();
//     }
//     delay(10); // 100Hz update rate
//   }
//   Serial.println("Target Reached.");
//   delay(1000); // Short pause between movements
// }

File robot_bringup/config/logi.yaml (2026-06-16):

amcl:
  ros__parameters:
    alpha1: 0.2
    alpha2: 0.2
    alpha3: 0.2
    alpha4: 0.2
    alpha5: 0.2
    base_frame_id: "base_footprint"
    beam_skip_distance: 0.5
    beam_skip_error_threshold: 0.9
    beam_skip_threshold: 0.3
    do_beamskip: false
    global_frame_id: "map"
    lambda_short: 0.1
    laser_likelihood_max_dist: 2.0
    laser_max_range: -1.0
    laser_min_range: -1.0
    laser_model_type: "likelihood_field"
    max_beams: 60
    max_particles: 2000
    min_particles: 500
    odom_frame_id: "odom"
    pf_err: 0.05
    pf_z: 0.99
    recovery_alpha_fast: 0.0
    recovery_alpha_slow: 0.0
    resample_interval: 1
    robot_model_type: "nav2_amcl::DifferentialMotionModel"
    save_pose_rate: 0.5
    sigma_hit: 0.2
    tf_broadcast: true
    transform_tolerance: 0.5
    update_min_a: 0.2
    update_min_d: 0.25
    z_hit: 0.5
    z_max: 0.05
    z_rand: 0.5
    z_short: 0.05
    scan_topic: /scan
    map_topic: map
    set_initial_pose: false
    always_reset_initial_pose: false
    first_map_only: false
    initial_pose:
      x: 0.0
      y: 0.0
      z: 0.0
      yaw: 0.0

bt_navigator:
  ros__parameters:
    global_frame: map
    robot_base_frame: base_link
    transform_tolerance: 0.5
    filter_duration: 0.3
    default_nav_to_pose_bt_xml: "$(find-pkg-share nav2_bt_navigator)/behavior_trees/navigate_to_pose_w_replanning_and_recovery.xml" # behavior trees location.
    default_nav_through_poses_bt_xml: "$(find-pkg-share nav2_bt_navigator)/behavior_trees/navigate_to_pose_w_replanning_and_recovery.xml"
    always_reload_bt_xml: false
    goal_blackboard_id: goal
    goals_blackboard_id: goals
    path_blackboard_id: path
    navigators: ['navigate_to_pose', 'navigate_through_poses']
    navigate_to_pose:
      plugin: "nav2_bt_navigator::NavigateToPoseNavigator"
    navigate_through_poses:
      plugin: "nav2_bt_navigator::NavigateThroughPosesNavigator"
    error_code_name_prefixes:
      - assisted_teleop
      - backup
      - compute_path
      - dock_robot
      - drive_on_heading
      - follow_path
      - nav_thru_poses
      - nav_to_pose
      - spin
      - route
      - undock_robot
      - wait

docking_server:
  ros__parameters:
    dock_plugins: ['nova_carter_dock']
    nova_carter_dock:
      plugin: 'opennav_docking::SimpleChargingDock'
    docks: ['home_dock','flex_dock1', 'flex_dock2']
    home_dock:
      type: 'nova_carter_dock'
      frame: map
      pose: [0.0, 0.0, 0.0]
    flex_dock1:
      type: 'nova_carter_dock'
      frame: map
      pose: [10.0, 10.0, 0.0]
    flex_dock2:
      type: 'nova_carter_dock'
      frame: map
      pose: [30.0, 30.0, 0.0]
    enable_stamped_cmd_vel: false

controller_server:
  ros__parameters:
    controller_frequency: 10.0
    min_x_velocity_threshold: 0.001
    min_y_velocity_threshold: 0.001
    min_theta_velocity_threshold: 0.001
    failure_tolerance: 0.3
    progress_checker_plugins: ["progress_checker"]
    goal_checker_plugins: ["goal_checker"]
    controller_plugins: ["FollowPath"]
    progress_checker:
      plugin: "nav2_controller::SimpleProgressChecker"
      required_movement_radius: 0.1
      movement_time_allowance: 10.0
    goal_checker:
      stateful: true
      plugin: "nav2_controller::SimpleGoalChecker"
      xy_goal_tolerance: 0.10
      yaw_goal_tolerance: 0.20
    FollowPath:
      plugin: "dwb_core::DWBLocalPlanner"
      debug_trajectory_details: true
      min_vel_x: 0.0
      min_vel_y: 0.0
      max_vel_x: 0.12
      max_vel_y: 0.0
      max_vel_theta: 0.35
      min_speed_xy: 0.0
      max_speed_xy: 0.12
      min_speed_theta: 0.0
      # Add high threshold velocity for turtlebot 3 issue.
      # https://github.com/ROBOTIS-GIT/turtlebot3_simulations/issues/75
      acc_lim_x: 0.25
      acc_lim_y: 0.0
      acc_lim_theta: 0.5
      decel_lim_x: -0.25
      decel_lim_y: 0.0
      decel_lim_theta: -0.5
      vx_samples: 20
      vy_samples: 0
      vtheta_samples: 40
      sim_time: 1.5
      linear_granularity: 0.05
      angular_granularity: 0.025
      transform_tolerance: 0.5
      xy_goal_tolerance: 0.10
      trans_stopped_velocity: 0.03
      short_circuit_trajectory_evaluation: true
      stateful: true
      critics: ["RotateToGoal", "Oscillation", "BaseObstacle", "GoalAlign", "PathAlign", "PathDist", "GoalDist"]
      BaseObstacle.scale: 1.0
      PathAlign.scale: 12.0
      PathAlign.forward_point_distance: 0.1
      GoalAlign.scale: 8.0
      GoalAlign.forward_point_distance: 0.1
      PathDist.scale: 12.0
      GoalDist.scale: 8.0
      RotateToGoal.scale: 8.0
      RotateToGoal.slowing_factor: 5.0
      RotateToGoal.lookahead_time: -1.0
    enable_stamped_cmd_vel: false
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

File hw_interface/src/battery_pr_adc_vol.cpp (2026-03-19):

#include "rclcpp/rclcpp.hpp"
#include <unistd.h>
#include <fcntl.h>
#include <sys/ioctl.h>
#include <linux/i2c-dev.h>
#include <cstdint>
#include <algorithm>

#define POINTER_CONVERSION  0x00
#define POINTER_CONFIG  0x01

#define VOLTAGE_DIVIDER_RATIO 5.0
#define BATTERY_MAX_V  25.0
#define BATTERY_MIN_V 20.0

using namespace std::chrono_literals;

struct BatteryData {
    double voltage;    // Actual battery voltage
    double percentage; // 0.0 to 100.0 %
};

class BattryVoltageNode : public rclcpp::Node 
{
    public: //puplic
        BattryVoltageNode() : Node("battery_voltage") 
        {
            this->declare_parameter("file_name","/dev/i2c-1");
            this->declare_parameter<int>("sensor_add",0x48);
            sensor_address_ = this->get_parameter("sensor_add").as_int();
            file_i2c_ = -1; //unset
            bus_file_name = this->get_parameter("file_name").as_string();
            timer_ = this->create_wall_timer(10s,std::bind(&BattryVoltageNode::timer_callback,this));


            RCLCPP_INFO(this->get_logger(),"The Battery node is running...");
        }
        
        
    private:

    bool init()
    {
        this->file_i2c_ = open(this->bus_file_name.c_str(),O_RDWR);
        if (this->file_i2c_ < 0)
        {
            RCLCPP_ERROR(this->get_logger(),"[ADC]FAILD TO OPEN I2C FILE ");
        }

        if (ioctl(this->file_i2c_,I2C_SLAVE,sensor_address_) < 0)
        {
            RCLCPP_ERROR(this->get_logger(),"[ADC] FAILD TO CONNECT TO THE SENSOR");
        }

        RCLCPP_INFO(this->get_logger(),"[ADC] Initialized successfully!");
        return true;
    }

    BatteryData ReadBatter()
    {
        BatteryData data = {0.0,0.0};
        
        uint8_t config[3] = {0x01, 0xC0, 0x83};;
        if (write(this->file_i2c_,config,3) != 3)
        {
            RCLCPP_ERROR(this->get_logger(),"[ADC] FAILD TO CONFIGURE THE SENSOR");
            return data;
        }
        usleep(10000);

        uint8_t reg[1]= {POINTER_CONVERSION};
        write(this->file_i2c_,reg,1);

        uint8_t comming_data[2] = {0};
        if (read(this->file_i2c_,comming_data, 2) != 2)
        {
            RCLCPP_ERROR(this->get_logger(),"[ADC] FAILD TO READ THE DATA FROM SENSOR");
            return data;
        }

        int16_t raw_adc = (comming_data[0] << 8) | comming_data[1];
        double adc_voltage = raw_adc * 0.0001875;
        data.voltage = adc_voltage * VOLTAGE_DIVIDER_RATIO;

        double raw_percentage = (
            (data.voltage - BATTERY_MIN_V) / (BATTERY_MAX_V - BATTERY_MIN_V)) * 100.0;

        data.percentage = std::clamp(raw_percentage, 0.0, 100.0);
        return data;
    }

    void timer_callback()
    {
        
    }

    int file_i2c_;
    int sensor_address_;
    std::string bus_file_name;
    rclcpp::TimerBase::SharedPtr timer_;

    

    
};

int main(int argc,char **argv)
{
    rclcpp::init(argc,argv);
    auto node = std::make_shared<BattryVoltageNode>();
    rclcpp::spin(node);
    rclcpp::shutdown();
    return 0;

}

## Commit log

2026-02-22 Fix comment and reformat Bluetooth test
    test_DC_Bluetooth.ino: close the header block comment at the top and remove the stray terminator at EOF, and perform code-style cleanups (brace placement, whitespace, macro alignment, switch/case indentation, and minor readability tweaks). test_DC_Movement/DC_Movement.cpp: remove an outdated comment about unused channel variables. These are formatting and comment fixes only; no functional logic changes.
2026-02-22 Add encoder-based drivetrain library and ROS bridge
    Remove the old single-file sketch and refactor drivetrain code into a reusable encoder-enabled implementation (DC_Movement_Encoder.hpp / DC_Movement_Encoder.cpp). Implements ISR wrappers, encoder cou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
2026-02-22 Add twistToPWM and expose motor setters
    Implement twistToPWM() in DC_Movement_Encoder.cpp to convert ROS Twist (linear_x, angular_z) into left/right PWM values: applies differential-drive kinematics, normalizes to -255..255 PWM using max_l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
2026-03-18 Initial commit: Add all ROS2 packages
    [BACKFACE.STL, CAMRAS.STL, FLANGE.STL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]
2026-03-18 update ultrasonic and uplaod iot and urdf
2026-03-18 Mpu6050 ros2_control update
    using ros2_control to achive the best accuracy from the mpu6050
    [mpu_controller.yaml]
2026-03-19 configure the controller
    configure the controller and the cpp file
    [mpu_controller.yaml, ros2_control.urdf.xacro]
2026-03-19 adc and voltage
    adding the adc and voltage sensors in c++
2026-05-01 the last tested version of the robot until now
    up dates in hw interface add the motor movement at ros2 control also lind blink
    the coming steps is the nema ros2 control controllers also the othere steps in the trial
    [chassis.urdf.xacro, common_prob.urdf.xacro, gazebo.urdf.xacro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]
2026-05-07 the final update
    this is the final update of the movement dc motor
2026-05-07 the final update of the nema motors
2026-05-07 Initial commit: Added ROS 2 and ESP32 architecture
    [my_robot_controllers.yaml, ros2_control.urdf.xacro]
2026-06-16 the final commit of the project
    [chassis.urdf.xacro, liDAR_SPACER.STL, lidar_spacer.STL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]
